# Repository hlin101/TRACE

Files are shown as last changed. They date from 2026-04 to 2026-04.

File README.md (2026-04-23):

# TRACE — Full Pipeline

TRACE is an end-to-end system for automated 2-D surface thickness scanning using stepper-motor-based linear actuators, an analog laser displacement sensor, Arduino for motor control and data acquisition, and MATLAB for cross-sectional area analysis.

---

## System Overview

```
┌─────────────────────────────────────────────────────────────┐
│                        Host PC                              │
│                                                             │
│   ArduinoDataAcquisition.m  ──►  scan_data.txt             │
│          │  (serial)                    │                   │
│          │                             ▼                    │
│          │                        csa_gui.m                 │
│          │                   (area / volume / 3D)           │
└──────────┼──────────────────────────────────────────────────┘
           │ COM / USB
┌──────────▼──────────────────────────────────────────────────┐
│                        Arduino                              │
│                                                             │
│  StepperMotorFullMotion.ino   ◄──  'G' command             │
│  StepperMotorController.ino   ◄──  W / A / S / D (manual)  │
│                                                             │
│  X stepper ── Y stepper ── Analog sensor (A0)              │
└─────────────────────────────────────────────────────────────┘
```

The two Arduino sketches are **loaded separately** depending on the mode needed (automated scan vs. manual stage jogging). Manual stage jogging is used to set starting position of scan. Automated scan is responsible for scanning and data collection. The two MATLAB files are run in sequence: acquisition first alongside automated scan, then the GUI for analysis.

---

## Repository Structure

```
.
├── StepperMotorFullMotion.ino    # Arduino: automated snake scan
├── StepperMotorController.ino   # Arduino: manual toggle control (stage jogging / setup)
├── ArduinoDataAcquisition.m     # MATLAB: serial trigger + data capture to .txt
└── csa_gui.m                    # MATLAB: cross-sectional area & volume analysis GUI
```

---

## Hardware Requirements

| Component | Notes |
|---|---|
| Arduino (Uno / Mega) | Tested at 9600 baud |
| 2× Stepper motor + driver | TMC2209 compatible; active-low EN pin |
| Panasonic laser displacement sensor | Outputs 0–5 V; wired to `A0` |
| NEMA 11 Linear Actuators | Wired to TMC2209 |
| USB cable | Arduino ↔ host PC |
| 12V DC Power Supply| Laser & Motor Power |

### Pin Assignments (both sketches)

| Signal | Pin |
|---|---|
| X Enable | 8 |
| X Step | 9 |
| X Direction | 10 |
| Y Enable | 5 |
| Y Step | 6 |
| Y Direction | 7 |
| Sensor (analog) | A0 |

---

## Software Requirements

| Tool | Version |
|---|---|
| Arduino IDE | 1.8+ or 2.x |
| MATLAB | R2019b or later |
| MATLAB toolboxes | None (base MATLAB only) |

---

## File Reference

### `StepperMotorFullMotion.ino` — Automated Scan

Flash this sketch when running a full acquisition. It waits for a `'G'` command over Serial, then performs a snake scan of the platform, sampling the analog sensor at each step and streaming `x_mm y_mm thickness_mm` triples back to the host.

**Key parameters (edit at top of file):**

| Constant | Default | Meaning |
|---|---|---|
| `X_STEP_SIZE` | `160` | Micro-steps per X increment |
| `Y_STEP_SIZE` | `3200` | Micro-steps per Y increment |
| `X_STEPS_TOTAL` | `300 × X_STEP_SIZE` | Total X travel |
| `Y_STEPS_TOTAL` | `15 × Y_STEP_SIZE` | Total Y travel |
| `STEP_DELAY` | `300 µs` | Pulse interval (controls speed) |
| `MM_PER_STEP` | `0.000625` | Stage calibration |
| `V_ZERO` | `2.49 V` | Sensor zero-offset voltage |
| `MM_PER_V` | `32.26` | Sensor sensitivity |
| `V_SATURATED` | `4.95 V` | Readings at or above this → `NaN` |

**Serial commands:**

| Command | Action |
|---|---|
| `G` | Start raster scan |
| `E` | Enable motors |
| `D` | Disable motors |

After the scan finishes, the stage returns to the origin automatically and the Arduino prints `FINISHED`.

---

### `StepperMotorController.ino` — Manual Toggle Control

Flash this sketch for stage setup, alignment, or sensor verification. Motors move continuously while a direction is active; sending the same key a second time stops that axis.

**Serial commands (case-insensitive):**

| Key | Action |
|---|---|
| `W` | Y axis — move down (toggle) |
| `S` | Y axis — move up (toggle) |
| `A` | X axis — move right (toggle) |
| `D` | X axis — move left (toggle) |
| `E` | Enable both motors |
| `H` | Disable both motors |

Speed is set by `stepDelay` (default `300 µs`). Open the Serial Monitor at **9600 baud** to send commands and read status messages.

---

### `ArduinoDataAcquisition.m` — MATLAB Data Capture

Connects to the Arduino over Serial, triggers a scan, captures all data lines, and writes them to `scan_data.txt`.

**Settings (edit at top of script):**

| Variable | Default | Meaning |
|---|---|---|
| `port` | `"COM5"` | Serial port of the Arduino |
| `baudRate` | `9600` | Must match the Arduino sketch |
| `fileName` | `"scan_data.txt"` | Output file path |

**Output file format:**
```
x_mm y_mm thickness_mm
0.0000 0.0000 0.0861
0.1000 0.0000 0.1042
...
```

The script ignores `STARTING_SCAN` status lines and stops recording when it receives `FINISHED`.

> **Note:** Change `"COM5"` to the correct port for your system (e.g. `"COM3"` on Windows, `"/dev/ttyUSB0"` on Linux, `"/dev/cu.usbmodem..."` on macOS).

---

### `csa_gui.m` — Cross-Sectional Area Analysis GUI

Loads the scan data file produced above and performs cross-sectional area and volume analysis via a graphical dashboard.

**Launch:**
```matlab
csa_gui
```

**Workflow:**
1. Click **Select Input File** and choose the `scan_data.txt` produced by `ArduinoDataAcquisition.m`.
2. The plot, stats strip, data table, and total volume label populate automatically.
3. Optionally click **Show 3D Model** for a rendered thickness surface.
4. Click **Save Area Data...** to export the per-slice area table as a `.txt` report.

**Key parameters (edit at top of `cb_load`):**

| Constant | Default | Effect |
|---|---|---|
| `Nintp` | `50` | Interpolation resolution along Y |
| `THRESHOLD` | `0.5` | Thickness ≤ this treated as zero (noise floor) |

---

## Typical Workflow

```
1. Flash StepperMotorController.ino
   └─ Use Serial Monitor to home / align the stage

2. Flash StepperMotorFullMotion.ino
   └─ Verify sensor reads correctly at rest

3. In MATLAB, run ArduinoDataAcquisition.m
   └─ Outputs: scan_data.txt

4. In MATLAB, run csa_gui
   └─ Load scan_data.txt → inspect area plot, 3D model, volume
   └─ Export area report if needed
```

---

## Calibration

All sensor calibration is contained in `StepperMotorFullMotion.ino`. To recalibrate for a different sensor or stage:

1. Measure the sensor output voltage at a known zero-thickness reference → update `V_ZERO`.
2. Measure at a known thickness target → recompute `MM_PER_V = thickness_mm / (V_measured - V_ZERO)`.
3. Measure stage travel per full step sequence → update `MM_PER_STEP`.
4. Adjust `THRESHOLD` in `csa_gui.m` to match the new noise floor.

---

## License

MIT — see [LICENSE](LICENSE) for details.

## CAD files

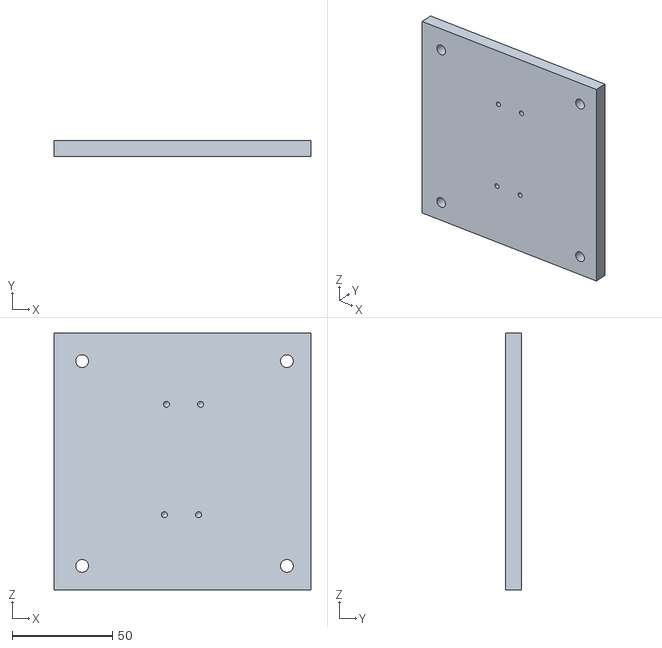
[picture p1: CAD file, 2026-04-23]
Newport-M-SA2-08X08 - Connector.stl
128.0 x 8.00 x 128.0

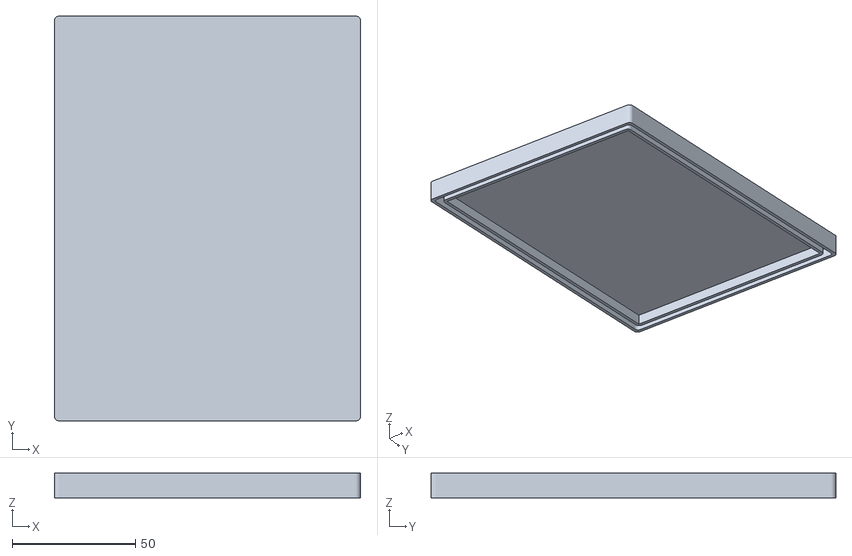
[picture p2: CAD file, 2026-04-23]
wires - lid.stl
124.0 x 164.0 x 10.0

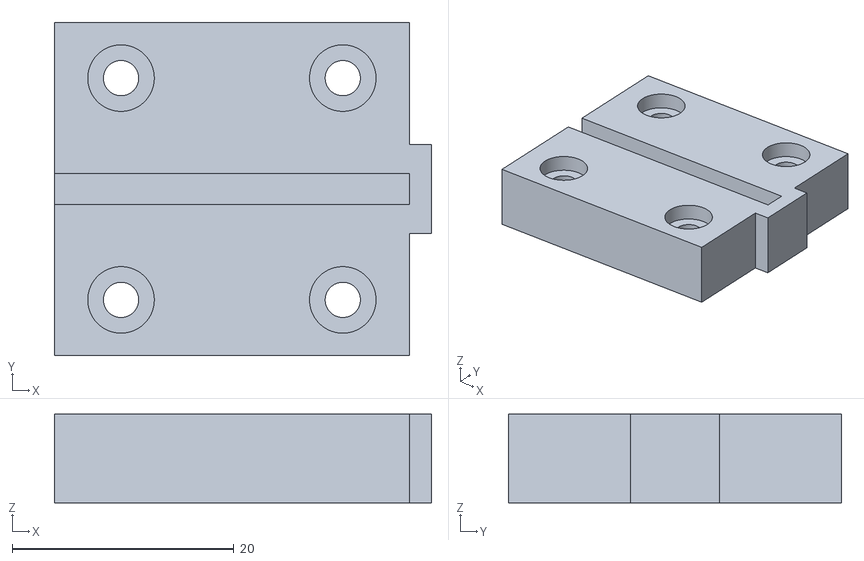
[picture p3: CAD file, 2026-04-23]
Stage - Base.stl
34.0 x 30.0 x 8.00

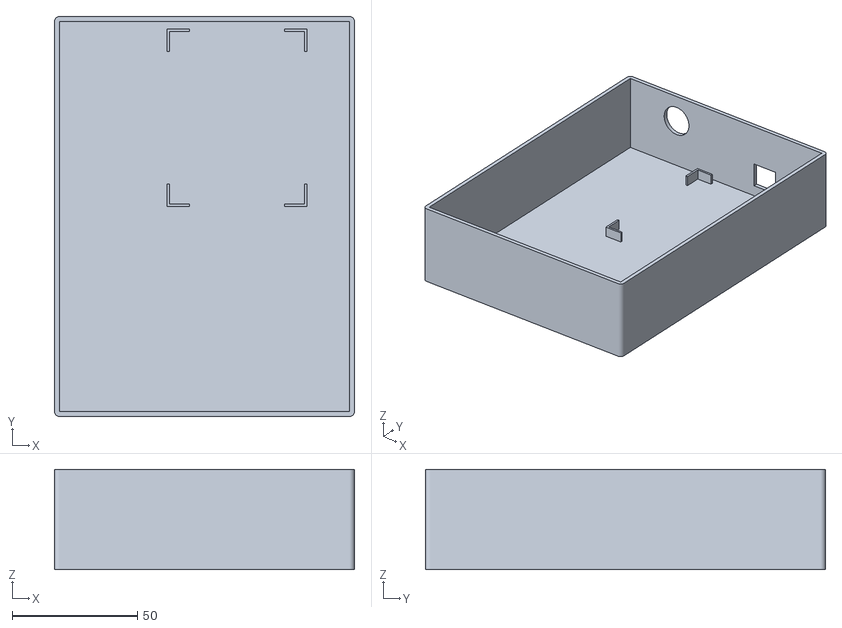
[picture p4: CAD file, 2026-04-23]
wires - container.stl
120.0 x 160.0 x 40.0

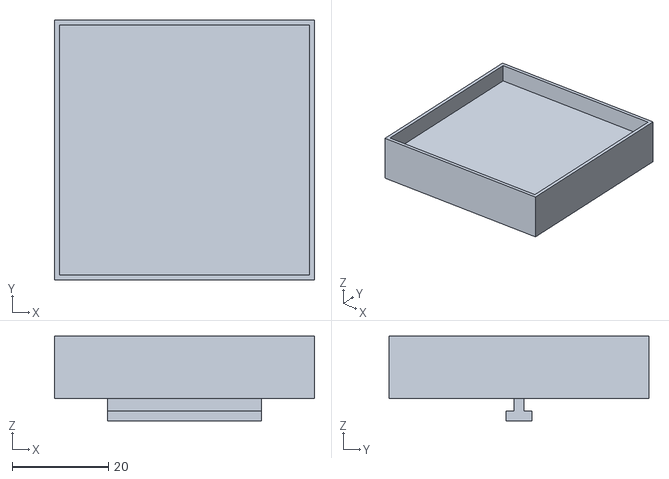
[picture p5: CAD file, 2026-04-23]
Stage - Stage.stl
54.0 x 54.0 x 17.6

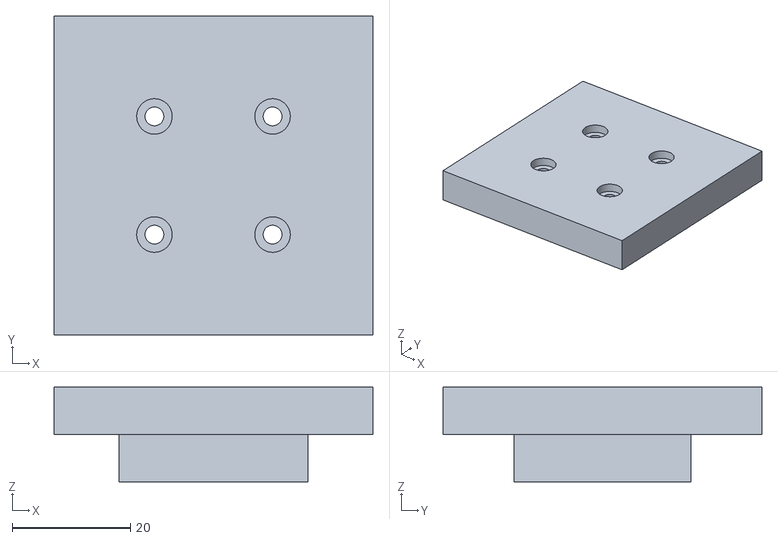
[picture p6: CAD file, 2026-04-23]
platform.stl
54.0 x 54.0 x 16.0

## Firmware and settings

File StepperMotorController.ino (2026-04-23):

// =============================================
// XY Stepper Motor Controller (TOGGLE VERSION)
// =============================================

// --- Pin Definitions ---
#define X_EN   8
#define X_STEP 9
#define X_DIR  10

#define Y_EN   5
#define Y_STEP 6
#define Y_DIR  7

// --- Config ---
int stepDelay = 300;
const int PULSE_WIDTH = 10;

// --- State variables ---
bool xMoving = false;
bool yMoving = false;

bool xDir = HIGH;
bool yDir = HIGH;

// =============================================
void setup() {
  Serial.begin(9600);

  pinMode(X_EN, OUTPUT);
  pinMode(X_STEP, OUTPUT);
  pinMode(X_DIR, OUTPUT);

  pinMode(Y_EN, OUTPUT);
  pinMode(Y_STEP, OUTPUT);
  pinMode(Y_DIR, OUTPUT);

  enableMotors();

  Serial.println("=== TOGGLE CONTROL ===");
  Serial.println("W/S toggle Y axis");
  Serial.println("A/D toggle X axis");
}

// =============================================
void loop() {

  // --- Handle input ---
  if (Serial.available() > 0) {
    char cmd = Serial.read();

    switch (cmd) {
      case 's': case 'S':
        if (yMoving && yDir == HIGH) {
          yMoving = false; // stop
          Serial.println("Y stopped");
        } else {
          yDir = HIGH;
          yMoving = true;
          Serial.println("Y moving UP");
        }
        break;

      case 'w': case 'W':
        if (yMoving && yDir == LOW) {
          yMoving = false;
          Serial.println("Y stopped");
        } else {
          yDir = LOW;
          yMoving = true;
          Serial.println("Y moving DOWN");
        }
        break;

      case 'd': case 'D':
        if (xMoving && xDir == LOW) {
          xMoving = false;
          Serial.println("X stopped");
        } else {
          xDir = LOW;
          xMoving = true;
          Serial.println("X moving LEFT");
        }
        break;

      case 'a': case 'A':
        if (xMoving && xDir == HIGH) {
          xMoving = false;
          Serial.println("X stopped");
        } else {
          xDir = HIGH;
          xMoving = true;
          Serial.println("X moving RIGHT");
        }
        break;

      case 'h': case 'H':
        disableMotors();
        Serial.println("Motors DISABLED");
        break;

      case 'e': case 'E':
        enableMotors();
        Serial.println("Motors ENABLED");
        break;
    }
  }

  // --- Continuous motion ---
  if (xMoving) {
    stepMotor(X_STEP, X_DIR, xDir);
  }

  if (yMoving) {
    stepMotor(Y_STEP, Y_DIR, yDir);
  }
}

// =============================================
void stepMotor(int stepPin, int dirPin, bool direction) {
  digitalWrite(dirPin, direction);
  digitalWrite(stepPin, HIGH);
  delayMicroseconds(PULSE_WIDTH);
  digitalWrite(stepPin, LOW);
  delayMicroseconds(stepDelay);
}

// =============================================
void enableMotors() {
  digitalWrite(X_EN, LOW);
  digitalWrite(Y_EN, LOW);
}

void disableMotors() {
  digitalWrite(X_EN, HIGH);
  digitalWrite(Y_EN, HIGH);
}

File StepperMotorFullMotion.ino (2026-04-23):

#define X_EN   8
#define X_STEP 9
#define X_DIR  10

#define Y_EN   5
#define Y_STEP 6
#define Y_DIR  7

#define SENSOR_PIN A0

// --- Parameters ---
const int  X_STEP_SIZE   = 160;
const int  Y_STEP_SIZE   = 3200;
const long X_STEPS_TOTAL = 300L * X_STEP_SIZE;
const long Y_STEPS_TOTAL = 15L  * Y_STEP_SIZE;
const int  STEP_DELAY    = 300;
const int  PULSE_WIDTH   = 10;

// --- Calibration ---
const float V_ZERO      = 2.49;
const float MM_PER_V    = 32.26;
const float ADC_REF     = 5.0;
const float MM_PER_STEP = 0.000625;
const float V_SATURATED = 4.95;

void setup() {
  Serial.begin(9600);
  pinMode(X_EN, OUTPUT); pinMode(X_STEP, OUTPUT); pinMode(X_DIR, OUTPUT);
  pinMode(Y_EN, OUTPUT); pinMode(Y_STEP, OUTPUT); pinMode(Y_DIR, OUTPUT);
  enableMotors();
  delay(1000); // sensor stabilise
}

void loop() {
  if (Serial.available() > 0) {
    char cmd = Serial.read();
    if (cmd == 'G') {
      Serial.println("STARTING_SCAN");
      rasterScan();
    }
    if (cmd == 'E') enableMotors();
    if (cmd == 'D') disableMotors();
  }
}

void rasterScan() {
  bool moveForward = true;
  long x_pos = 0;
  long y_pos = 0;

  for (long y = 0; y < Y_STEPS_TOTAL; y += Y_STEP_SIZE) {
    digitalWrite(X_DIR, moveForward ? HIGH : LOW);

    for (long x = 0; x < X_STEPS_TOTAL; x += X_STEP_SIZE) {
      stepMotor(X_STEP, X_STEP_SIZE);

      if (moveForward) x_pos += X_STEP_SIZE;
      else             x_pos -= X_STEP_SIZE;

      delay(5);

      int   adc       = analogRead(SENSOR_PIN);
      float voltage   = (adc / 1023.0) * ADC_REF;
      float x_mm      = x_pos * MM_PER_STEP;
      float y_mm      = y_pos * MM_PER_STEP;

      Serial.print(x_mm, 4); Serial.print(" ");
      Serial.print(y_mm, 4); Serial.print(" ");

      if (voltage >= V_SATURATED) {
        Serial.println("NaN");
      } else {
        float thickness = (voltage - V_ZERO) * MM_PER_V;
        thickness = max(thickness, 0.0);  // clamp negatives to 0
        Serial.println(thickness, 4);
      }
    }

    digitalWrite(Y_DIR, HIGH);
    stepMotor(Y_STEP, Y_STEP_SIZE);
    y_pos += Y_STEP_SIZE;
    moveForward = !moveForward;
  }

  // --- Return to Origin ---
  if (x_pos != 0) {
    digitalWrite(X_DIR, (x_pos > 0) ? LOW : HIGH);
    stepMotor(X_STEP, abs(x_pos));
  }
  digitalWrite(X_EN, HIGH);  // disable X during Y return
  delay(50);
  digitalWrite(Y_DIR, LOW);
  stepMotor(Y_STEP, y_pos);
  digitalWrite(X_EN, LOW);   // re-enable X after

  Serial.println("FINISHED");
}

void stepMotor(int stepPin, long steps) {
  for (long i = 0; i < steps; i++) {
    digitalWrite(stepPin, HIGH);
    delayMicroseconds(PULSE_WIDTH);
    digitalWrite(stepPin, LOW);
    delayMicroseconds(STEP_DELAY);
  }
}

void enableMotors()  { digitalWrite(X_EN, LOW);  digitalWrite(Y_EN, LOW);  }
void disableMotors() { digitalWrite(X_EN, HIGH); digitalWrite(Y_EN, HIGH); }
